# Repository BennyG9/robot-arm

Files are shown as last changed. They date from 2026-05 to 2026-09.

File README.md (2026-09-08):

# Robotic Arm Project (Ongoing)

STM32-based robotic arm project focused on embedded control systems and robotic system design. The long-term goal is a 4-5 DOF manipulator with ROS2 integration, computer vision, and AI-assisted task execution using an NVIDIA Jetson Nano. This project is a work in progress and is documented regularly...
<br><br>
Here are some videos demonstrating the current progress:
* [3-DOF Robotic Arm Calibration and Homing (7-22-2026)](https://youtu.be/QVaRYJWts_0)
* [ROS2 Full Teleoperation (7-10-2026)](https://youtu.be/LquclRMNV8o)
* [Embedded Communication System & Basic ROS2 Teleoperation (7-7-2026)](https://youtu.be/_pa4kOoXHEc)
* [Base & Shoulder Calibration and Homing (6-14-2026)](https://youtu.be/knIQMhBv_wg)
* [PID Position Control Demo (5-29-2026)](https://youtu.be/YCUa2xMnsVE)

Project Started: May 2026
<br>
Last Documentation Update: 9/8/2026

## Project Goals 

* Design and build a Multi-DOF robotic arm
* Implement real-time control system for precise mechanics
* Enable AI functionality using computer vision on NVIDIA Jetson Nano
* Design custom PCB integrating power systems, embedded processing, and motor driving

## Status 

### Completed
* Shoulder, base, and elbow joints electro-mechanical prototypes
* 3-DOF PID positional control using STM32
* STM32 embedded firmware architecture
* ROS2 Jetson Nano software architecture
* 3-DOF calibration and homing procedures
* Jetson Nano - STM32 USB serial communication and ROS2 Teleoperation
* 3-joint forward kinematics, inverse kinematics in MATLAB
* Linear trajectory planning 

### In Progress
* ROS2 kinematics integration
* PID tuning for all joints

### Planned
* 3-DOF mechanics and control, ultimately expand to 4 or 5 DOF
* NVIDIA Jetson Nano + STM32 distributed system for high-level planning and real-time control
* RTOS implementation 
* ROS2 package for high-level robot interfacing
* AI and computer vision integration
* Custom PCB design

## How it Works 

### Mechanical Design
---
<div>
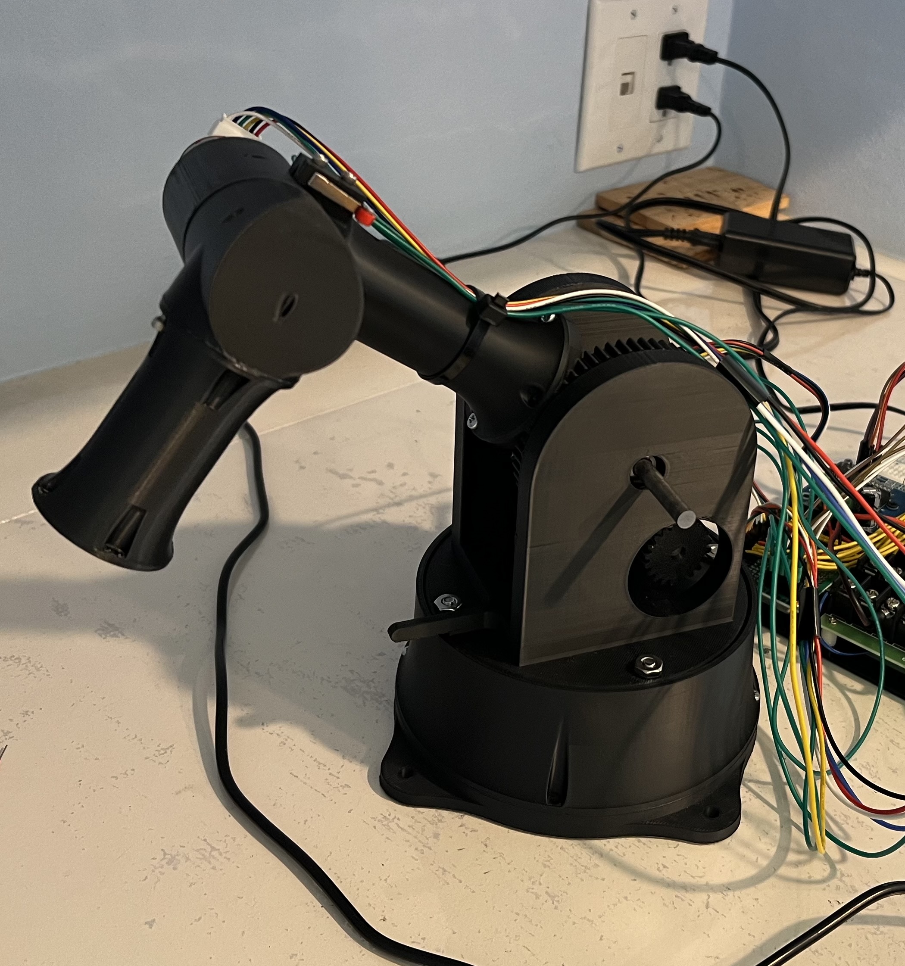
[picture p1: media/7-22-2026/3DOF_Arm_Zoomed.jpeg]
   
  <p>The mechanical structure is being developed using OnShape. The current prototype shows basic 3-DOF design. The design distributes mechanical loads through dedicated bearings rather than motor shafts and maximizes torque closer to the joints. The new design improves stiffness and reduces footprint from the previous version. The design builds in limit switches for joint position calibration. <br><br> Next steps: redesign motor couplers for less backlash</p>
  <br clear="right" />
</div>

### Embedded Architecture 
---
<div>
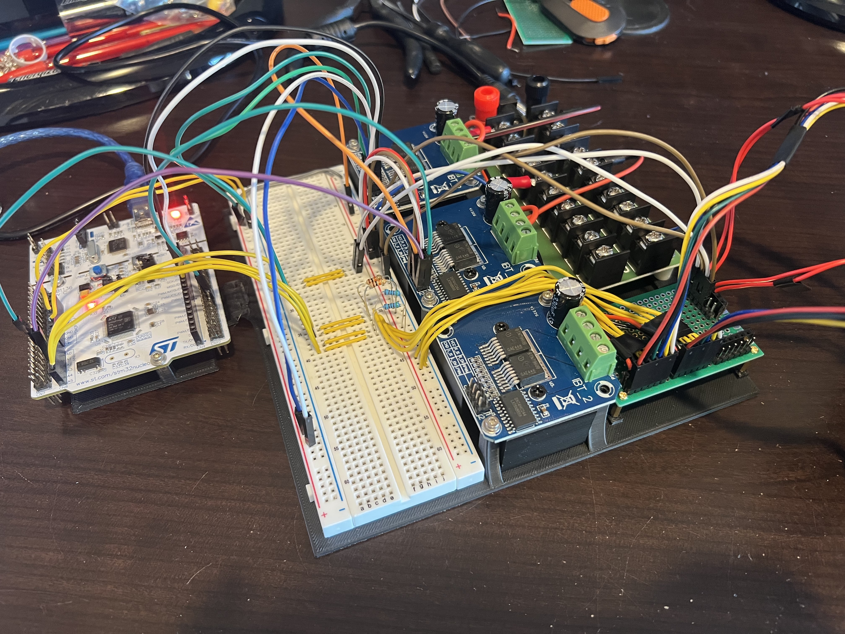
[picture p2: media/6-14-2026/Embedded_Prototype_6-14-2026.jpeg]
   
  
  <p>The robotic arm is powered by an STM32 Nucleo-F446RE, responsible for all of the real-time control code. Motors are driven by IBT-2 type motor driver modules rated for up to 43A. The system uses a custom serial USB communication protcol defined in JSON and supports variable argument length with checksum packet verification. The Jetson Nano runs ROS2 Foxy with custom services, launch files, and communication nodes. Only basic calibration and homing teleoperation commands are supported currently.<br><br> Next steps: ROS2 teleop angular control, ROS2 high-level kinematics</p>
  <br clear="right" />
</div>

[Embedded Communication System & Basic ROS2 Teleoperation (7-7-2026)](https://youtu.be/_pa4kOoXHEc)<br>
[ROS2 Full Teleoperation (7-10-2026)](https://youtu.be/LquclRMNV8o)

### Control
---
<div>
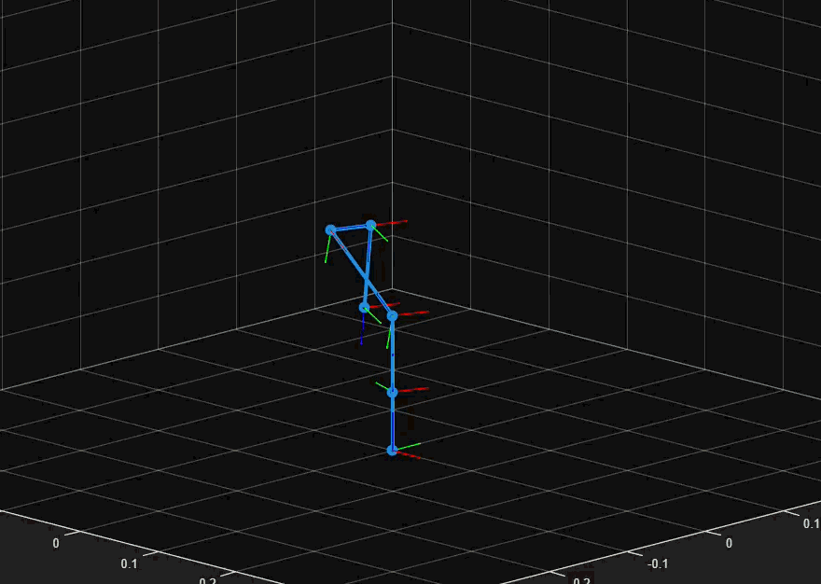
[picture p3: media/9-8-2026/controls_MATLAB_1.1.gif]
  

  <p>The shoulder, base, and elbow joints currently uses a 1kHz closed-loop PID controller running on an STM32F446RE. Joint position is determined using an encoder updated every control loop cycle. The motors are driven using IBT-2 type motor driver modules. Each joint has a calibration procedure using limit switches. Forward Kinematics (using transformation matrices), Inverse Kinematics, and Linear Trajectory planning are all implemented and simulated in MATLAB. <br><br> Next steps: Time Parameterization, ROS Kinematics & Trajectory Integration </p>

  <br clear="right" />
</div>

[3-DOF Robotic Arm Calibration and Homing (7-22-2026)](https://youtu.be/QVaRYJWts_0)

## Technical Stack

### Hardware
* STM32 Nucleo F446RE
* NVIDIA Jetson Nano (planned)
* IBT-2 Motor Driver Modules
* Geared DC Motors with Encoders
### Software
* C (STM32)
* ROS2 Foxy (Jetson Nano)
* MATLAB (Kinematics Simulation)
### Design Tools 
* OnShape (CAD)
* STM32CubeMX & STM32CubeIDE
* PuTTY & NoMachine
* Git

## Repository Structure 
````text
robotic-arm/
├── communication/
├── config/
│   └── URDF/
├── controls/
│   ├── Kinematics/
│   ├── Trajectory/
│   └── Visualization/
├── firmware/ 
│   └── arm_stm32/
├── hardware/
│   ├──  CAD/
│   └──  KiCAD/
├── media/
├── software/
│   └── arm_ros2_ws/
└── README.md
````

## Code Structure
* `communication/` - Defines and builds serial communication protocol
* `config/` - Defines robot configuration and important variables
  * `config/URDF/` - Contains robot description and xacro variables build
* `controls/` - MATLAB control code, simulation, and visualization
  * `controls/Kinematics/` - Forward and inverse kinematics implementation
  * `controls/Trajectory/` - Trajectory generation and path planning
  * `controls/Visualization/` - Robot visualization
* `firmware/arm_stm32/` - STM32 project main folder
  * `firmware/arm_stm32/Core/Src/` - Source files for STM32 real-time embedded control
  * `firmware/arm_stm32/Core/Inc/` - Header files for embedded code
* `software/arm_ros2_ws/` - ROS2 workspace
  * `software/arm_ros2_ws/src/arm_bringup/` - ROS2 launch files
  * `software/arm_ros2_ws/src/arm_description/` - URDF package 
  * `software/arm_ros2_ws/src/arm_interfaces/` - ROS2 custom services source code
  * `software/arm_ros2_ws/src/arm_teleop/` - ROS2 teleoperation nodes
  * `software/arm_ros2_ws/src/kinematics/` - ROS2 kinematics & related nodes
  * `software/arm_ros2_ws/src/stm32_bridge/` - Jetson Nano & STM32 serial communication package
  * `software/arm_ros2_ws/src/trajectory/` - Trajectory planning nodes

## Media 

[3-DOF Robotic Arm Calibration and Homing (7-22-2026)](https://youtu.be/QVaRYJWts_0)
[ROS2 Full Teleoperation (7-10-2026)](https://youtu.be/LquclRMNV8o)<br>
[Embedded Communication System & ROS2 Teleoperation (7-7-2026)](https://youtu.be/_pa4kOoXHEc) <br>
[Base & Shoulder Calibration and Homing (6-14-2026)](https://youtu.be/knIQMhBv_wg) <br>
[PID Position Control Demo (5-28-2026)](https://youtu.be/YCUa2xMnsVE)

<div align="left">
  
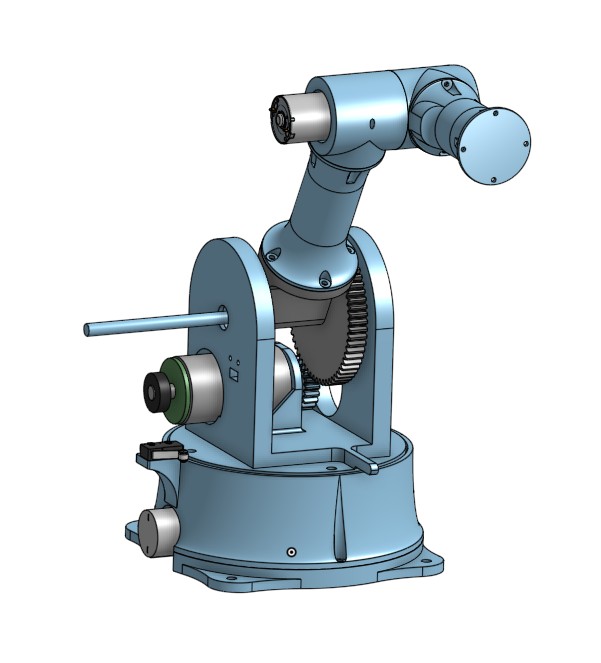
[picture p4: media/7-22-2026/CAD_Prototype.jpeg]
  
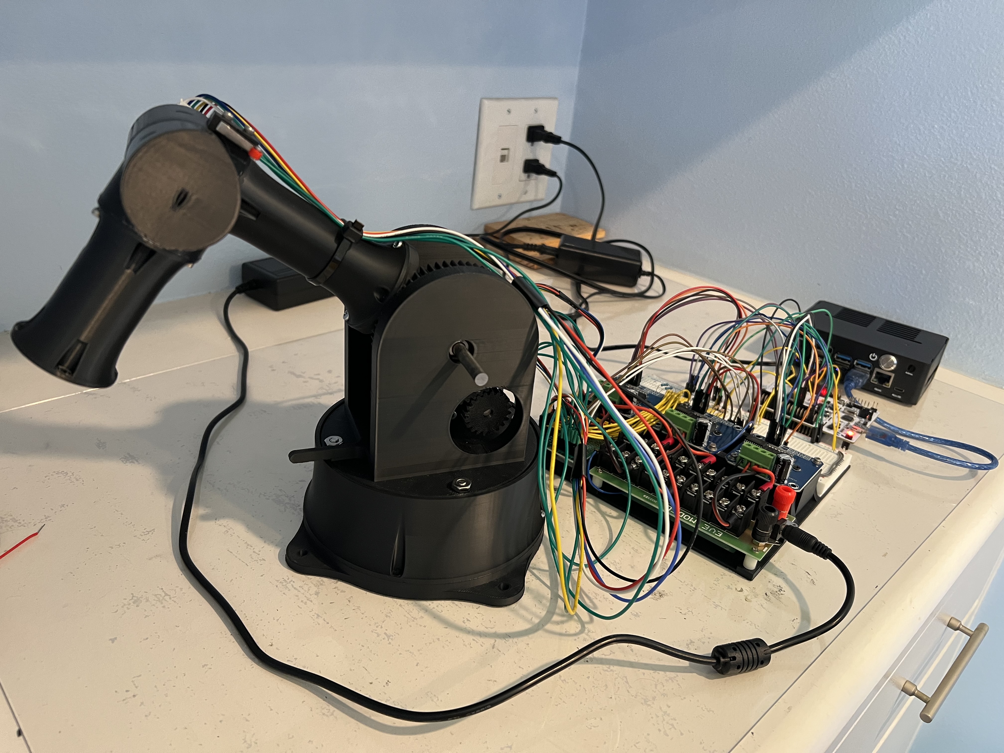
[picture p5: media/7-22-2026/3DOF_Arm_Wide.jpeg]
  
  
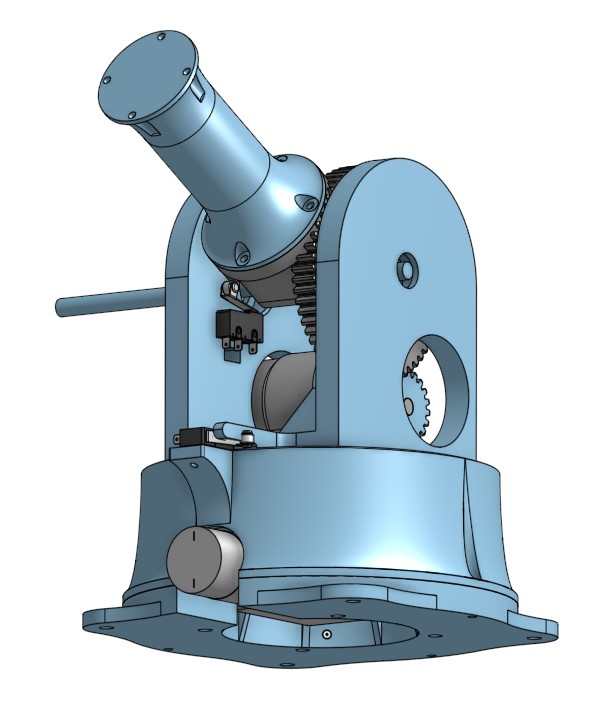
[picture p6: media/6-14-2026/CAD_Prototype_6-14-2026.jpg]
  
  
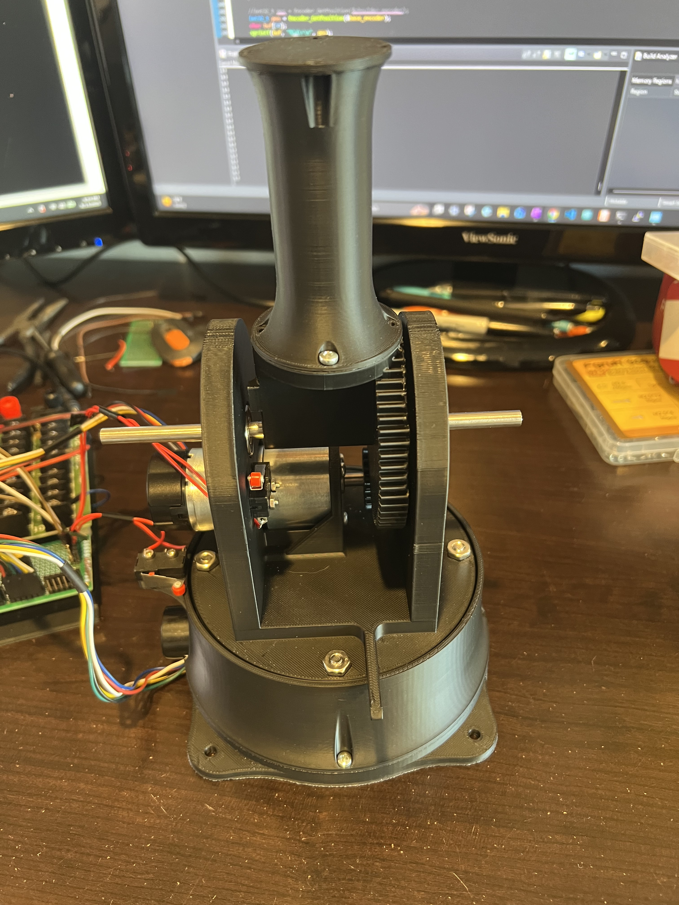
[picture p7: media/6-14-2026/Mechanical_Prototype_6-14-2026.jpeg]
  
  <br clear="left" />
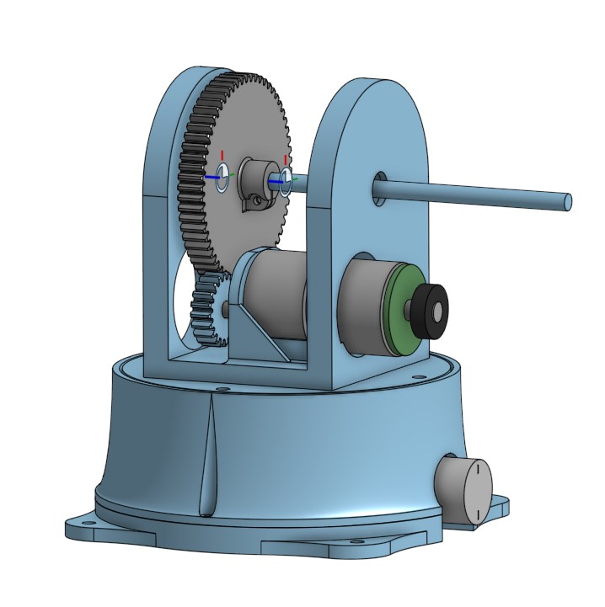
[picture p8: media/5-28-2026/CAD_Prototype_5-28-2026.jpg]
  
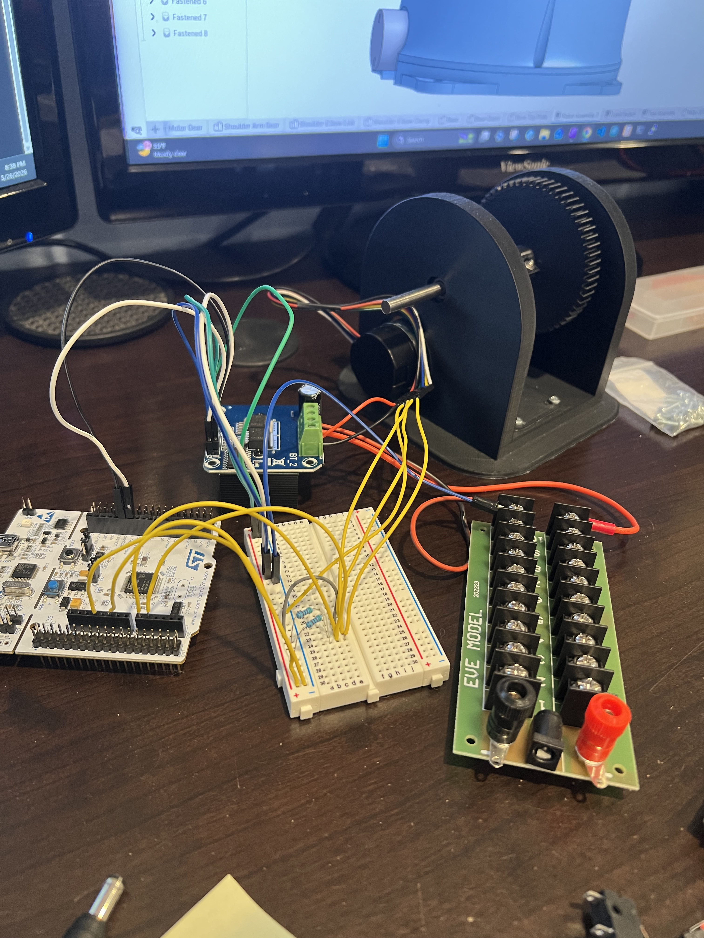
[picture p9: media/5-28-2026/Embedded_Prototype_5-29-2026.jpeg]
  
</div>

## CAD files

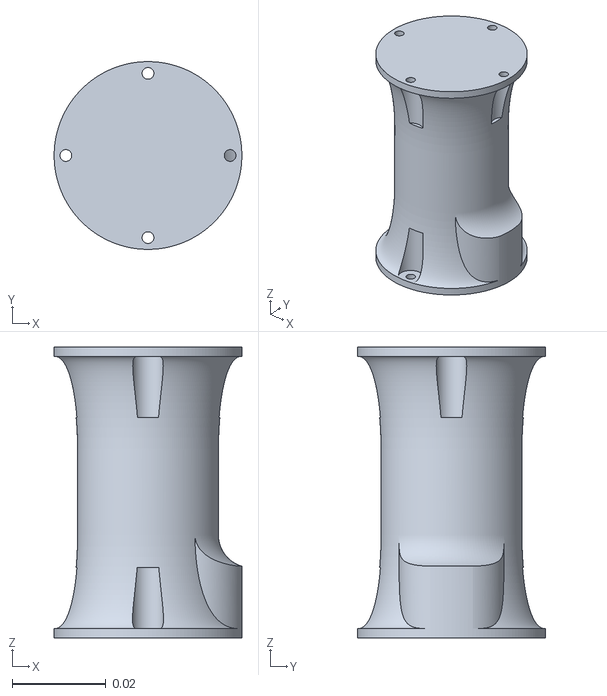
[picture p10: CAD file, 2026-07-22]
hardware/CAD/Elbow-Wrist_Link.stl
0.04 x 0.04 x 0.062

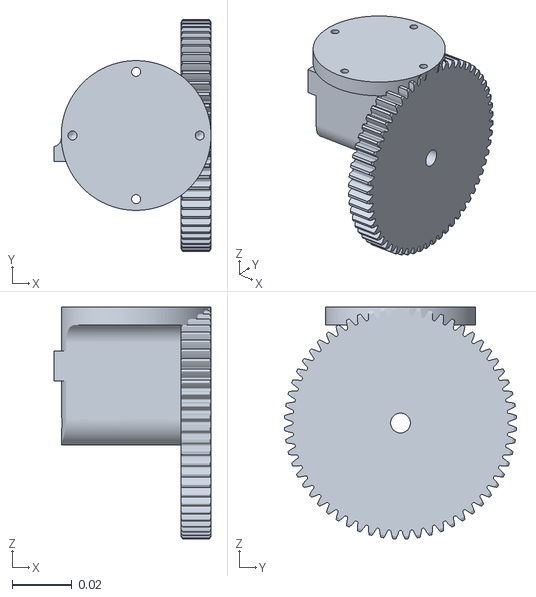
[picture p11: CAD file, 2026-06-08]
hardware/KiCAD/Robotic_Arm/CAD/Shoulder_Gear_Hub.stl
0.0524 x 0.0774 x 0.0775

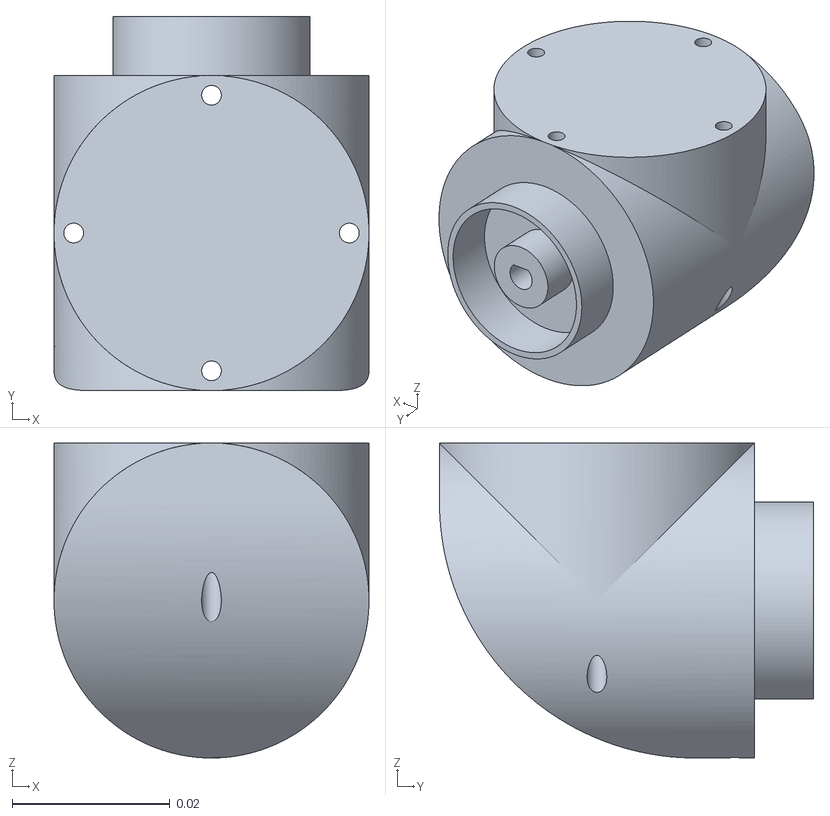
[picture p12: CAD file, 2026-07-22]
hardware/CAD/Elbow_Joint_Hub.stl
0.04 x 0.0475 x 0.04

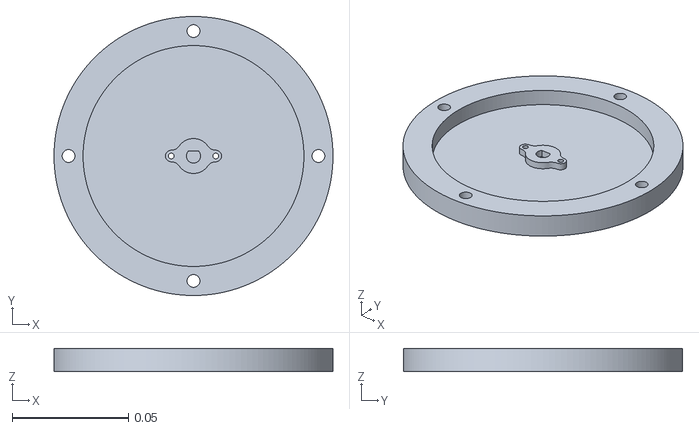
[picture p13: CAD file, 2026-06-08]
hardware/KiCAD/Robotic_Arm/CAD/Base_Top_Plate.stl
0.12 x 0.12 x 0.01

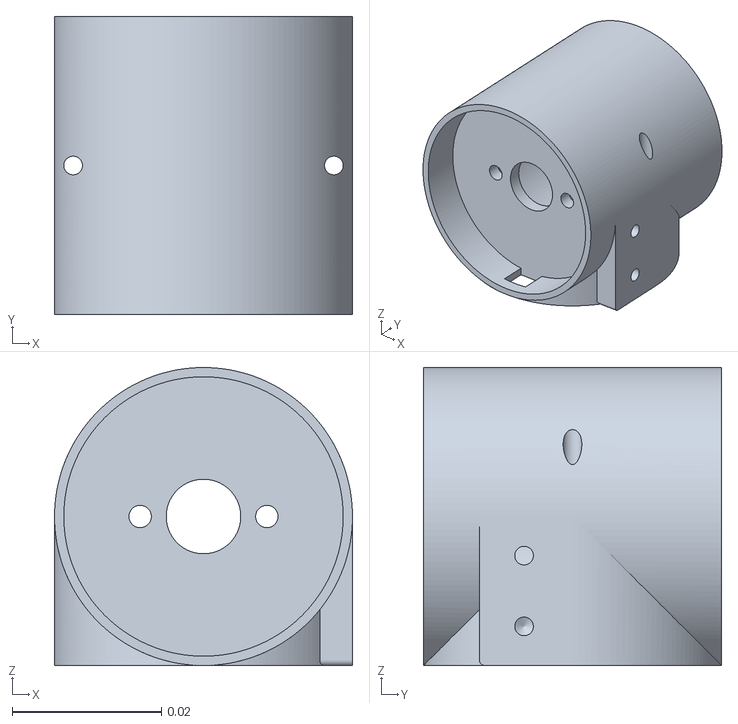
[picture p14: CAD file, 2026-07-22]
hardware/CAD/Elbow_Joint.stl
0.04 x 0.04 x 0.04

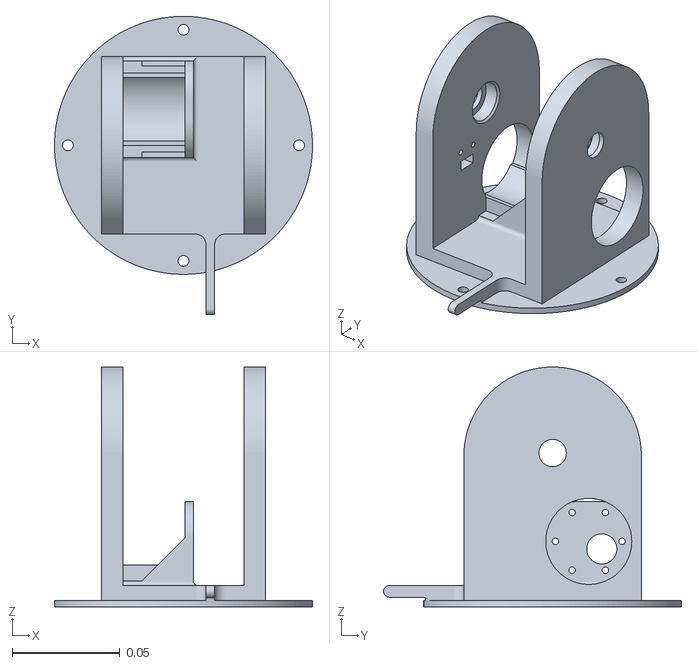
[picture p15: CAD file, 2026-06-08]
hardware/KiCAD/Robotic_Arm/CAD/Shoulder_Joint_Housing.stl
0.12 x 0.139 x 0.112

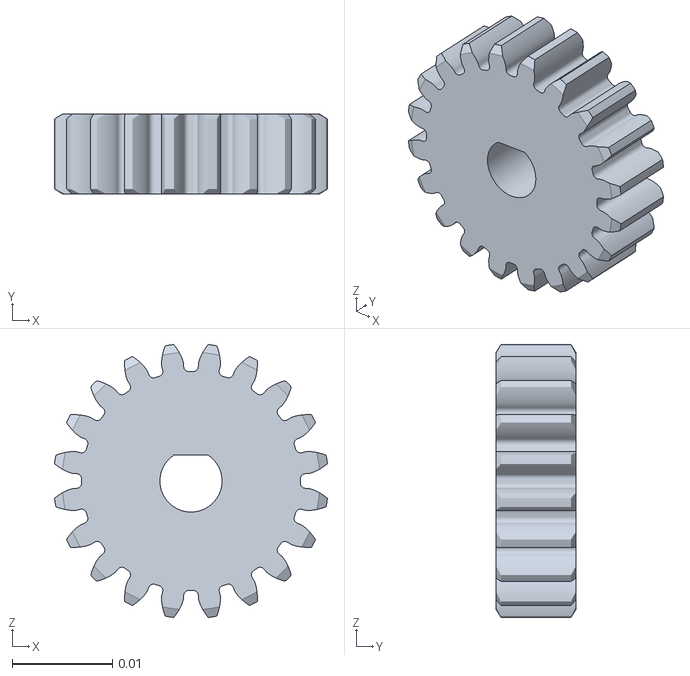
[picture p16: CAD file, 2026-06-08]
hardware/KiCAD/Robotic_Arm/CAD/Shoulder_Motor_Gear.stl
0.0273 x 0.008 x 0.0273

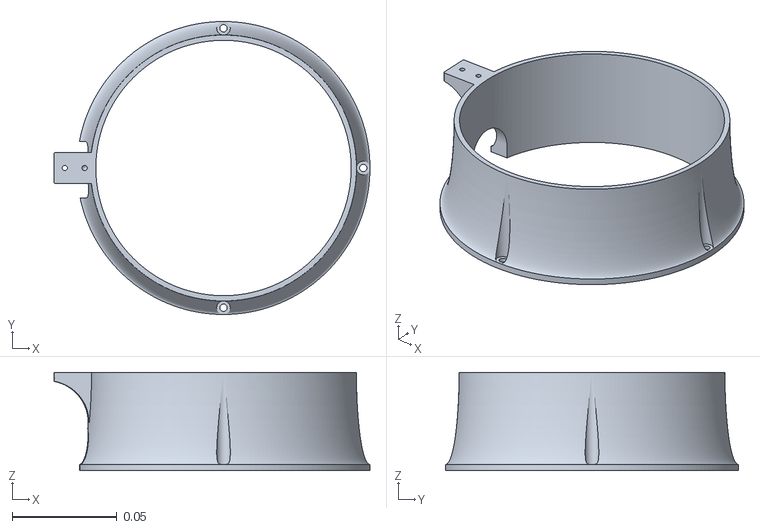
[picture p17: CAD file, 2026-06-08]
hardware/CAD/Base_Cover.stl
0.151 x 0.14 x 0.047

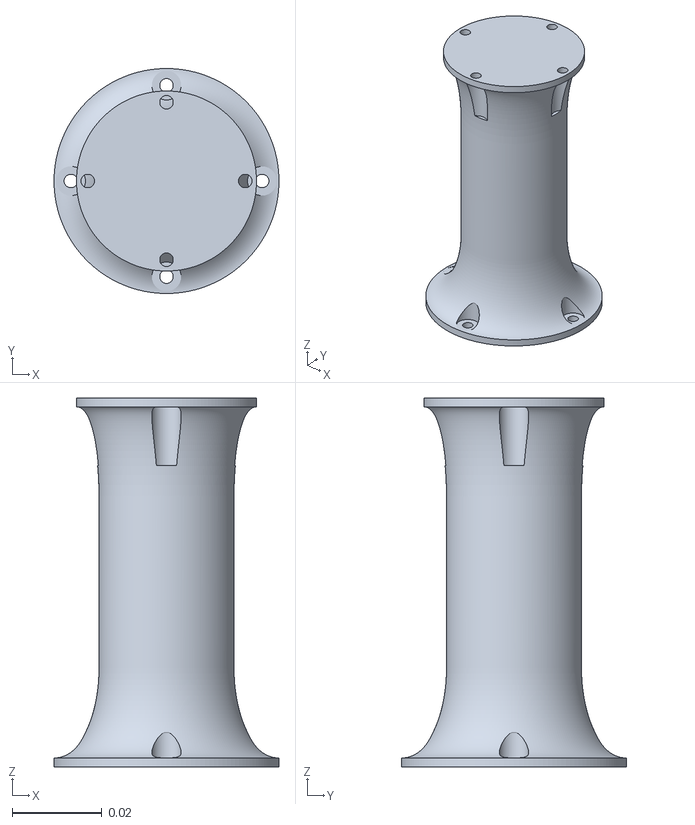
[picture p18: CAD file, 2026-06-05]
hardware/KiCAD/Robotic_Arm/CAD/Shoulder-Elbow_Link.stl
0.05 x 0.05 x 0.082

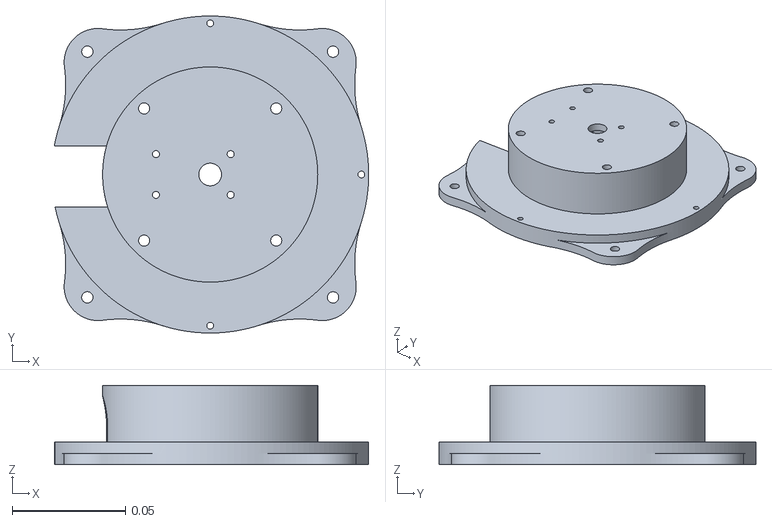
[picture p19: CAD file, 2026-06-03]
hardware/KiCAD/Robotic_Arm/CAD/Base_Bottom.stl
0.139 x 0.14 x 0.035

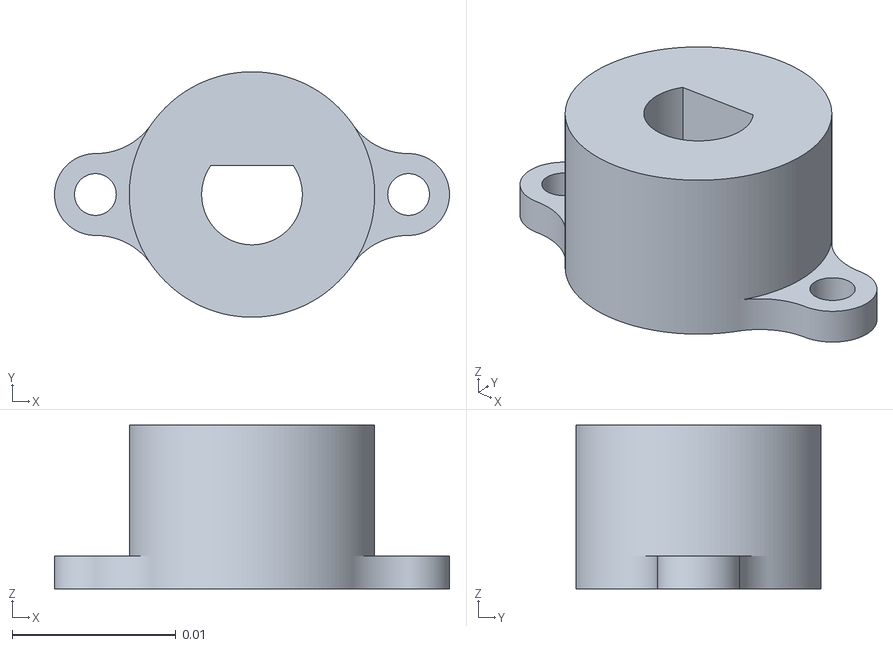
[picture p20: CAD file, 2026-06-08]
hardware/CAD/Base_Motor_Coupler.stl
0.0241 x 0.015 x 0.01

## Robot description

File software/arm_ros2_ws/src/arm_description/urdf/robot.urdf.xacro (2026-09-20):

<?xml version="1.0"?>
<robot xmlns:xacro="http://www.ros.org/wiki/xacro" name="robot_arm">

    <xacro:include filename="robot_variables.xacro"/>

    <kinematic_parameters base_height="${base_height}" L1="${L1}" L2="${L2}" L3="${L3}" base_joint_min="${base_joint_min}" base_joint_max="${base_joint_max}" shoulder_joint_min="${shoulder_joint_min}" shoulder_joint_max="${shoulder_joint_max}" elbow_joint_min="${elbow_joint_min}" elbow_joint_max="${elbow_joint_max}" elbow_joint_offset="${elbow_joint_offset}" />

    <link name = "gnd_base_link">
        <visual>
            <origin xyz="0 0 0" rpy="0 0 0"/>
        </visual>
    </link>

    <link name = "base_shoulder_link">
        <visual>
            <origin xyz="0 0 0" rpy="0 0 0"/>
        </visual>
    </link>

    <link name = "shoulder_elbow_link">
        <visual>
            <origin xyz="0 0 0" rpy="0 0 0"/>
        </visual>
    </link>

    <link name = "elbow_end_effector_link">
        <visual>
            <origin xyz="0 0 0" rpy="0 0 0"/>
        </visual>
    </link>

    <link name = "end_effector_link">
        <visual>
            <origin xyz="0 0 0" rpy="0 0 0"/>
        </visual>
    </link>


    <joint name="base_joint" type="revolute">
        <parent link="gnd_base_link"/>
        <child link="base_shoulder_link"/>

        <origin xyz="0 0 ${base_height}" rpy="0 0 0"/>
        <axis xyz="0 0 -1"/>

        <limit lower="${base_joint_min}" upper="${base_joint_max}" effort="2.0" velocity="2.0"/>
    </joint>

    <joint name="shoulder_joint" type="revolute">
        <parent link="base_shoulder_link"/>
        <child link="shoulder_elbow_link"/>

        <origin xyz="0 0 ${L1}" rpy="0 0 0"/>
        <axis xyz="-1 0 0"/>

        <limit lower="${shoulder_joint_min}" upper="${shoulder_joint_max}" effort="2.0" velocity="2.0"/>
    </joint>

    <joint name="elbow_joint" type="revolute">
        <parent link="shoulder_elbow_link"/>
        <child link="elbow_end_effector_link"/>

        <origin xyz="${elbow_joint_offset} 0 ${L2}" rpy="0 0 0"/>
        <axis xyz="1 0 0"/>

        <limit lower="${elbow_joint_min}" upper="${elbow_joint_max}" effort="2.0" velocity="2.0"/>
    </joint>

    <joint name="end_effector_joint" type="fixed">
        <parent link="elbow_end_effector_link"/>
        <child link="end_effector_link"/>

        <origin xyz="0 0 ${L3}" rpy="0 0 0"/>
    </joint>

</robot>

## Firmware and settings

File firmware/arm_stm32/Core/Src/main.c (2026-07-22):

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
/* Includes ------------------------------------------------------------------*/
#include "main.h"

/* USER CODE BEGIN Includes */

#include "motor.h"
#include "encoder.h"
#include "pid.h"
#include "joint.h"
#include "serial.h"
#include "protocol.h"
#include "serial_monitor.h"
/* USER CODE END Includes */

TIM_HandleTypeDef htim2;
TIM_HandleTypeDef htim3;
TIM_HandleTypeDef htim4;
TIM_HandleTypeDef htim6;
TIM_HandleTypeDef htim8;
TIM_HandleTypeDef htim12;

UART_HandleTypeDef huart2;

/* USER CODE BEGIN PV */
static Joint shoulder_joint;
static Joint base_joint;
static Joint elbow_joint;

//enum State {
//	IDLE,
//	CAL,
//	CONTR,
//};
//enum State state = IDLE;

uint8_t rx_byte;
Packet packet;

uint8_t joint_publish_flag = 0;
uint8_t joint_calibrate_flag = 0;
uint8_t joint_control_flag = 0;

static uint16_t JOINT_PUBLISH_FREQ = 100;  //Hz
uint16_t joint_publish_counter = 0;
/* USER CODE END PV */

void SystemClock_Config(void);
static void MX_GPIO_Init(void);
static void MX_USART2_UART_Init(void);
static void MX_TIM3_Init(void);
static void MX_TIM2_Init(void);
static void MX_TIM6_Init(void);
static void MX_TIM4_Init(void);
static void MX_TIM8_Init(void);
static void MX_TIM12_Init(void);
/**
  * @brief  The application entry point.
  * @retval int
  */
int main(void)
{

  /* MCU Configuration--------------------------------------------------------*/

  /* Reset of all peripherals, Initializes the Flash interface and the Systick. */
  HAL_Init();

  /* Configure the system clock */
  SystemClock_Config();

  /* Initialize all configured peripherals */
  MX_GPIO_Init();
  MX_USART2_UART_Init();
  MX_TIM3_Init();
  MX_TIM2_Init();
  MX_TIM6_Init();
  MX_TIM4_Init();
  MX_TIM8_Init();
  MX_TIM12_Init();
  /* USER CODE BEGIN 2 */


  HAL_StatusTypeDef status = HAL_TIM_Encoder_Start(&htim2, TIM_CHANNEL_ALL);
  HAL_TIM_Encoder_Start(&htim4, TIM_CHANNEL_ALL);
  HAL_TIM_Encoder_Start(&htim8, TIM_CHANNEL_ALL);

  if(status != HAL_OK){
	  HAL_GPIO_WritePin(GPIOA, GPIO_PIN_5, GPIO_PIN_SET);
	  while(1);
  }

  HAL_TIM_Base_Start_IT(&htim6);

  HAL_TIM_PWM_Start(&htim3, TIM_CHANNEL_1);
  HAL_TIM_PWM_Start(&htim3, TIM_CHANNEL_2);
  HAL_TIM_PWM_Start(&htim3, TIM_CHANNEL_3);
  HAL_TIM_PWM_Start(&htim3, TIM_CHANNEL_4);
  __HAL_TIM_SET_COMPARE(&htim3, TIM_CHANNEL_1, 0);
  __HAL_TIM_SET_COMPARE(&htim3, TIM_CHANNEL_2, 0);
  __HAL_TIM_SET_COMPARE(&htim3, TIM_CHANNEL_3, 0);
  __HAL_TIM_SET_COMPARE(&htim3, TIM_CHANNEL_4, 0);

  HAL_TIM_PWM_Start(&htim12, TIM_CHANNEL_1);
  HAL_TIM_PWM_Start(&htim12, TIM_CHANNEL_2);
  __HAL_TIM_SET_COMPARE(&htim12, TIM_CHANNEL_1, 0);
  __HAL_TIM_SET_COMPARE(&htim12, TIM_CHANNEL_2, 0);
  /* USER CODE END 2 */

  /* Infinite loop */
  /* USER CODE BEGIN WHILE */


  //SHOULDER JOINT DECLARATION
  Motor shoulder_motor = {.timer=&htim3, .forward_channel=TIM_CHANNEL_1, .reverse_channel=TIM_CHANNEL_2, .min_duty_forward=50, .min_duty_reverse=-75};
  Encoder shoulder_encoder = {.timer=&htim2, .offset=0, .resolution=12576};
  PID shoulder_pid = {.Kp=1.0f, .Ki=0.0f, .Kd=0.0f, .integral=0, .prev_error=0};
  Joint_Init(&shoulder_joint, &shoulder_motor, &shoulder_encoder, &shoulder_pid, S_Limit_Switch_Pin, 0, 78.0, -90.0);

  //BASE JOINT DECLARATION
  Motor base_motor = {.timer=&htim3, .forward_channel=TIM_CHANNEL_3, .reverse_channel=TIM_CHANNEL_4, .min_duty_forward=100, .min_duty_reverse=-100};
  Encoder base_encoder = {.timer=&htim4, .offset=0, .resolution=7040};
  PID base_pid = {.Kp=3.5f, .Ki=0.0f, .Kd=0.0f, .integral=0, .prev_error=0};
  Joint_Init(&base_joint, &base_motor, &base_encoder, &base_pid, B_Limit_Switch_Pin, 0, 80.0, -90.0);

  //ELBOW JOINT DECLARATION
  Motor elbow_motor = {.timer=&htim12, .forward_channel=TIM_CHANNEL_1, .reverse_channel=TIM_CHANNEL_2, .min_duty_forward=100, .min_duty_reverse=-100};
  Encoder elbow_encoder = {.timer=&htim8, .offset=0, .resolution=11000};
  PID elbow_pid = {.Kp=3.5f, .Ki=0.0f, .Kd=0.0f, .integral=0, .prev_error=0};
  Joint_Init(&elbow_joint, &elbow_motor, &elbow_encoder, &elbow_pid, E_Limit_Switch_Pin, 0, 119.0, -90.0);

  joint_control_flag = 0;

  //serial initialization
  Serial_Init(&huart2);
  HAL_UART_Receive_IT(&huart2, &rx_byte, 1);
  SerialMonitor_Init();


  while (1)
  {

//	  if(HAL_GPIO_ReadPin(GPIOC, GPIO_PIN_13) == GPIO_PIN_RESET){
//		  Motor_SetPower(&shoulder_motor, -300);
//	  }else{
//		  Motor_SetPower(&shoulder_motor, 0);
//	  }
//
//	  if(HAL_GPIO_ReadPin(GPIOC, E_Limit_Switch_Pin) == GPIO_PIN_SET){
//		  HAL_GPIO_WritePin(GPIOA, GPIO_PIN_5, GPIO_PIN_SET);
//	  }else{
//		  HAL_GPIO_WritePin(GPIOA, GPIO_PIN_5, GPIO_PIN_RESET);
//	  }
//
//	  //int32_t pos = Encoder_GetPosition(&shoulder_encoder);
//	  char buf[32];
//	  sprintf(buf, "%ld\r\n", __HAL_TIM_GET_COUNTER(&htim2));
//	  HAL_UART_Transmit(&huart2, (uint8_t*)buf, strlen(buf), HAL_MAX_DELAY);


	  if(joint_publish_flag == 1){
		  Protocol_WriteCommand(JOINT_STATE, Joint_GetAngle(&base_joint), Joint_GetAngle(&shoulder_joint), Joint_GetAngle(&elbow_joint));
		  joint_publish_flag = 0;
	  }

	  if(joint_calibrate_flag == 1){
		  joint_control_flag = 0;
		  HAL_GPIO_TogglePin(GPIOA, GPIO_PIN_5);
		  Joint_Calibrate(&base_joint);
		  HAL_Delay(250);
		  Joint_Calibrate(&shoulder_joint);
		  HAL_Delay(250);
		  Joint_Calibrate(&elbow_joint);
		  HAL_Delay(250);
		  joint_calibrate_flag = 0;
		  joint_control_flag = 1;
	  }



    /* USER CODE END WHILE */

    /* USER CODE BEGIN 3 */
  }
  /* USER CODE END 3 */
}

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
/* USER CODE BEGIN 4 */




void HAL_TIM_PeriodElapsedCallback(TIM_HandleTypeDef* htim){
	if(htim->Instance == TIM6){

		// update limit switch indicators
//		if(HAL_GPIO_ReadPin(GPIOC, S_Limit_Switch_Pin) == GPIO_PIN_SET || HAL_GPIO_ReadPin(GPIOC, B_Limit_Switch_Pin) == GPIO_PIN_SET){
//			HAL_GPIO_WritePin(GPIOA, GPIO_PIN_5, GPIO_PIN_SET);
//		}else{
//			HAL_GPIO_WritePin(GPIOA, GPIO_PIN_5, GPIO_PIN_RESET);
//		}


		// state control
//		switch(state){
//			case CONTR:
//				Joint_Update(&shoulder_joint);
//				Joint_Update(&base_joint);
//				break;
//			case IDLE:
//				break;
//			case CAL:
//				break;
//		}c
		if(joint_control_flag == 1){
			Joint_Update(&shoulder_joint);
			Joint_Update(&base_joint);
			Joint_Update(&elbow_joint);
		}

		// serial monitoring

		if(Protocol_ReadPacket(&packet) == HAL_OK){
			switch((CommandID)packet.command){
				case JOINT_STATE:
					break;

				case SET_POSITION:
					float positions[3];
					int byte_index = 0;
					for(int float_index = 0; float_index < 3; float_index++){
						memcpy(&(positions[float_index]), &(packet.args[byte_index]), sizeof(float));
						byte_index += 4;
					}
					Joint_SetTargetAngle(&base_joint, positions[0]);
					Joint_SetTargetAngle(&shoulder_joint, positions[1]);
					Joint_SetTargetAngle(&elbow_joint, positions[2]);
					HAL_GPIO_TogglePin(GPIOA, GPIO_PIN_5);
					break;

				case CALIBRATE:
					joint_calibrate_flag = 1;
					break;

				case HOME:
					Joint_SetTargetAngle(&base_joint, 0.0f);
					Joint_SetTargetAngle(&shoulder_joint, 0.0f);
					Joint_SetTargetAngle(&elbow_joint, 0.0f);
					break;

				case SET_PID:
					break;

				case ESTOP:
					break;

				case ERROR_MSG:
					break;
			}
		}


		joint_publish_counter++;
		if(joint_publish_counter >= (uint16_t)(1000 / JOINT_PUBLISH_FREQ)){
			joint_publish_counter = 0;
			joint_publish_flag = 1;
		}

	}

}

void HAL_UART_RxCpltCallback(UART_HandleTypeDef* huart){
	if(huart->Instance == USART2){
		SerialMonitor_Append(rx_byte);
		HAL_UART_Receive_IT(huart, &rx_byte, 1);
	}
}

//void HAL_UART_ErrorCallback(UART_HandleTypeDef* huart){
//	if(huart->Instance == USART2){
//		uint32_t err = HAL_UART_GetError(huart);
//		Protocol_WriteError((uint8_t)err);
//		Protocol_WriteError((uint8_t)huart->RxState);
//		Protocol_WriteError((uint8_t)huart->gState);
//		HAL_StatusTypeDef status = HAL_UART_Receive_IT(huart, &rx_byte, 1);
//		Protocol_WriteError((uint8_t)status);
//	}
//}






/* USER CODE END 4 */
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


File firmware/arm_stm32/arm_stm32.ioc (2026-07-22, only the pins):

Mcu.UserName=STM32F446RETx
PA13.GPIO_Label=TMS
PA13.Signal=SYS_JTMS-SWDIO
PA14.GPIO_Label=TCK
PA14.Signal=SYS_JTCK-SWCLK
PA15.GPIO_Label=S_ENC_A
PA15.Signal=S_TIM2_CH1_ETR
PA2.GPIO_Label=USART_TX
PA2.Signal=USART2_TX
PA3.GPIO_Label=USART_RX
PA3.Signal=USART2_RX
PA5.GPIO_Label=LD2 [Green Led]
PA5.Signal=GPIO_Output
PA6.GPIO_Label=S_MTR_F
PA6.Signal=S_TIM3_CH1
PA7.GPIO_Label=S_MTR_B
PA7.Signal=S_TIM3_CH2
PB0.GPIO_Label=B_MTR_F
PB0.Signal=S_TIM3_CH3
PB1.GPIO_Label=B_MTR_B
PB1.Signal=S_TIM3_CH4
PB14.GPIO_Label=E_MTR_B
PB14.Signal=S_TIM12_CH1
PB15.GPIO_Label=E_MTR_F
PB15.Signal=S_TIM12_CH2
PB3.GPIO_Label=SWO
PB3.Signal=SYS_JTDO-SWO
PB6.GPIO_Label=B_ENC_B
PB6.Signal=S_TIM4_CH1
PB7.GPIO_Label=B_ENC_A
PB7.Signal=S_TIM4_CH2
PB9.GPIO_Label=S_ENC_B
PB9.Signal=S_TIM2_CH2
PC0.GPIO_Label=S_Limit_Switch
PC0.Signal=GPIO_Input
PC1.GPIO_Label=B_Limit_Switch
PC1.Signal=GPIO_Input
PC13.Signal=GPIO_Input
PC14-OSC32_IN.Signal=RCC_OSC32_IN
PC15-OSC32_OUT.Signal=RCC_OSC32_OUT
PC2.GPIO_Label=E_Limit_Switch
PC2.Signal=GPIO_Input
PC6.GPIO_Label=E_ENC_B
PC6.Signal=S_TIM8_CH1
PC7.GPIO_Label=E_ENC_A
PC7.Signal=S_TIM8_CH2
PH0-OSC_IN.Signal=RCC_OSC_IN
PH1-OSC_OUT.Signal=RCC_OSC_OUT

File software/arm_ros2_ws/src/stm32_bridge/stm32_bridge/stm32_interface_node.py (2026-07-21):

import rclpy
from rclpy.node import Node
#from sensor_msgs.msg import JointState
from arm_interfaces.srv import Calibrate
from arm_interfaces.srv import Home
from arm_interfaces.msg import JointStates
from arm_interfaces.msg import JointTargets

from .protocol import Protocol

import time
import math

class STM32Bridge(Node):

    def __init__(self):
        super().__init__('stm32_bridge')

        #Serial communication
        self.protocol = Protocol()

        #Joint State publisher
        #self.joint_pub = self.create_publisher(JointState, "joint_states", 10)
        self.joint_pub = self.create_publisher(JointStates, "joint_states", 10)

        #Joint Target listener
        self.joint_sub = self.create_subscription(JointTargets, "joint_targets", self.joint_targets_callback, 10)

        #Services
        self.calibrate_srv = self.create_service(
            Calibrate,
            "calibrate",
            self.calibrate_callback
        )

        self.home_srv = self.create_service(
            Home,
            "home",
            self.home_callback
        )

        #Communication loop
        self.timer = self.create_timer(0.0001, self.read_serial)

        #Clear serial
        self.protocol.clear_serial()

        self.get_logger().info("STM32 Bridge Initiated")
        pass

    def read_serial(self):

        # check for packet
        packet = self.protocol.read_packet()

        if(packet == None):
            return
        if(packet == -1):
            print("CHECKSUM ERROR")
            return

        # parse packet
        command, args = self.protocol.parse_packet(packet)

        # executables
        if(self.protocol.get_direction(command) == "JETSON_TO_STM32"):
            pass

        if(command == "JOINT_STATE"):
            self.publish_joint_states(args[0])
            pass

        elif(command == "ERROR_MSG"):
            self.get_logger().info("ERROR CODE: " + str(args[0][0]))
            #print("ERROR CODE: " + str(args[[0]]))
            pass

        pass


    def calibrate_callback(self, request, response):
        self.get_logger().info("Calibrate Command Sent")
        self.protocol.write_packet("CALIBRATE")
        response.success = True
        return response


    def home_callback(self, request, response):
        self.get_logger().info("Home Command Sent")
        self.protocol.write_packet("HOME")
        response.success = True
        return response


    def publish_joint_states(self, joint_angles):
        msg = JointStates()
        msg.base = joint_angles[0]
        msg.shoulder = joint_angles[1]
        msg.elbow = joint_angles[2]
        self.joint_pub.publish(msg)
        pass


    def joint_targets_callback(self, msg):
        self.protocol.write_packet("SET_POSITION", msg.base, msg.shoulder, msg.elbow)
        pass

    pass


def main():
    rclpy.init()
    node = STM32Bridge()
    rclpy.spin(node)
    node.destroy_node()
    rclpy.shutdown()


if __name__ == "__main__":
    main()

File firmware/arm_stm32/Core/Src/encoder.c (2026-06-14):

/*
 * encoder.c
 *
 *  Created on: May 22, 2026
 *      Author: Benjamin Goldstein
 */

#include "encoder.h"

int32_t Encoder_GetPosition(Encoder* encoder){
	int32_t raw_pos = (int16_t)__HAL_TIM_GET_COUNTER(encoder->timer);

	return raw_pos - encoder->offset;
}


void Encoder_Zero(Encoder* encoder){
	//encoder->offset = (int16_t)__HAL_TIM_GET_COUNTER(encoder->timer);
	__HAL_TIM_SET_COUNTER(encoder->timer, 0);
}

float Encoder_CountToAngle(Encoder* encoder, int16_t count){
	float inc = 360.0f / ((float)encoder->resolution);
	return ((float)count) * inc;
}

int16_t Encoder_AngleToCount(Encoder* encoder, float angle){
	float inc = ((float)encoder->resolution) / 360.0;
	return (int16_t)(angle * inc);
}


float Encoder_GetAngle(Encoder* encoder){
	//float inc = 360.0 / ((float)encoder->resolution);
	//float angle = ((float)Encoder_GetPosition(encoder)) * inc;
	float angle = Encoder_CountToAngle(encoder, Encoder_GetPosition(encoder));
	return angle;
}


void Encoder_SetAngle(Encoder* encoder, float angle){
	//float inc = ((float)encoder->resolution) / 360.0;
	//int16_t new_pos = (int16_t)(angle * inc);
	int16_t new_pos = Encoder_AngleToCount(encoder, angle);
	__HAL_TIM_SET_COUNTER(encoder->timer, new_pos);
}

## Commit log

2026-05-20 basic motor functionality
2026-05-22 abstracted motor PWM code
2026-05-22 abstracted encoder code
2026-05-22 abstracted PID control
2026-05-22 abstracted joint functionality
2026-05-23 added timer for 1kHz control loop
2026-05-23 added minimum forward and reverse duty cycle for motor abstraction
    [main.c, motor.c]
2026-05-28 added CAD prototype screenshot
2026-06-01 added KiCAD project files
    [Robotic_Arm.kicad_pcb, Robotic_Arm.kicad_sch]
2026-06-08 Updated CAD files
    [Base_Bottom.stl, Base_Cover.stl, Base_Motor_Coupler.stl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]
2026-06-08 moved files
    [Base_Bottom.stl, Base_Cover.stl, Base_Motor_Coupler.stl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]
2026-06-12 set up code for base motor functionality
2026-06-12 added limit switch firmware
2026-06-13 developing homing sequence for calibration
2026-06-13 completed calibration sequence, ready for testing
2026-06-14 calibration and homing complete
2026-06-14 added set target angle/pos for joint structures
2026-06-18 added ROS2 framework, started serial communication node
2026-06-20 test code bug fix
    [main.c]
2026-06-21 begun testing, checksum error
    [protocol.py]
2026-06-22 write packet functionality for jetson
2026-06-24 serial writing too fast
    [protocol.py]
2026-06-24 now UART reads serial on interrupt and logs bytes in serial monitor
2026-06-24 working serial monitor using interrupts
2026-06-25 float parsing bug fixes
    [protocol.py]
2026-06-27 publish joint states
2026-06-27 joint state publishing firmware
2026-06-29 change joint publish frequency to 100 Hz
2026-06-30 added error flags for testing
    [main.c]
2026-07-01 fixed no arg packet reading in firmware
    [main.c, protocol.c]
2026-07-05 debugging flags
    [arm_stm32.cfg]
2026-07-06 firmware interrupt blocking fix
    [main.c, serial_monitor.c]
2026-07-08 started work on customizing ROS2 joint topics
2026-07-20 started adding elbow motor to firmware
2026-07-21 added thrid joint to comm protocol
2026-08-09 forward kinematics
2026-08-09 inverse kinematics
2026-08-30 split base link into 2 parts for better ROS integration
    [robot.urdf.xacro]
2026-08-30 xacro variable generation + basic robot description
    [robot.urdf.xacro, robot_variables.xacro]
2026-09-16 kinematics nodes restructure
2026-09-17 moving over to Jetson
2026-09-20 parsing URDF, now working on grabbing that info from robot_model_node
    [robot.urdf.xacro]
2026-09-27 added tests for kinematics in teleop
2026-09-29 build success state
    [robot.urdf.xacro, robot_variables.xacro]
2026-10-06 fixed some issues with service calls, frame dimensions
2026-10-08 updated how kinematics are used
2026-10-08 changed teleop to use kinematics code directly rather than via service
2026-10-14 added motor speed limits to the robot description
2026-10-20 working on STM32 interface for ROS2 trajectory
2026-11-11 threaded logging to solve blocking issue

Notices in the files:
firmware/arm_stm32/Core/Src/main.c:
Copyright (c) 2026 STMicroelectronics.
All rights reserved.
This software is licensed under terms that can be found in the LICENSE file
